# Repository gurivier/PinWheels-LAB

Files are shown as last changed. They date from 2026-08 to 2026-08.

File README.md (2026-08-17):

# PinWheels@LAB

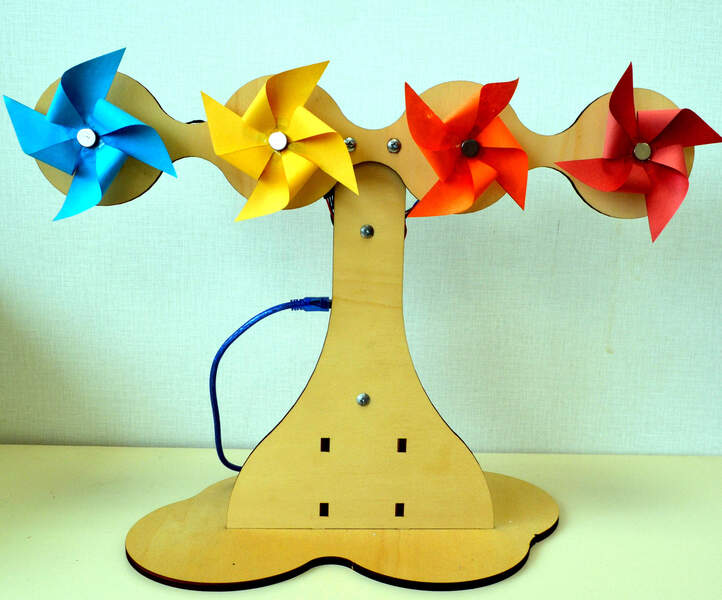
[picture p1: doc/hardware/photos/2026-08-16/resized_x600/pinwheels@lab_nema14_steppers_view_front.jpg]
Photo of a PinWheels@LAB specimen built in March 2023.


**PinWheels@LAB** is a display device that rotates four pinwheels to convey information ambiently. This small device, that teachers can bring into the classroom or install in school labs, is a tribute to the PinWheels installation<sup>(1)</sup> from the MIT Tangible Media Lab. Beyond extending Python programming lessons to data treatment and IoT communication, PinWheels@LAB enables students' thinking about innovative ways to convey information and to feel physical data representation in their classroom.

(1) Hiroshi Ishii, Sandia Ren, and Phil Frei. 2001. Pinwheels: visualizing information flow in an architectural space. In CHI '01 Extended Abstracts on Human Factors in Computing Systems (CHI EA '01). Association for Computing Machinery, New York, NY, USA, 111–112. [https://doi.org/10.1145/634067.634135](https://doi.org/10.1145/634067.634135)

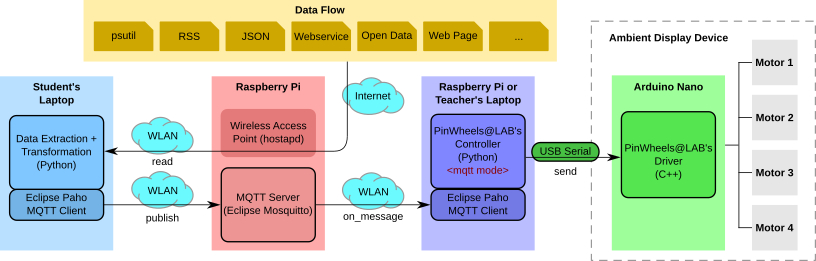
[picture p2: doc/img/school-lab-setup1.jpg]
Overview of the communication layers of PinWheels@LAB in a school lab: the student's laptop runs an application that sends messages to an MQTT brocker, which then distributes this message to PinWheels@LAB's Python controller on the teacher's laptop. Then, the controller sends the message to PinWhee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


_Bring an ambient display in the classroom!_

## Getting Started

### Prerequisites

* Python &ge; 3.15 is required ([downloads](https://www.python.org/downloads/))
  * The controller has been tested on Python version 3.15.5.

* Eclipse Mosquitto server &ge; 2.0 ([downloads](https://mosquitto.org))
    * The controller has been tested with Mosquitto version 2.0.21 and Callback API version 2
    * Check configuration in the mosquitto.conf file (e.g., `/etc/mosquitto/mosquitto.conf`):
        * `listener 1883 0.0.0.0`
        * `allow_anonymous true`

* Arduino IDE &ge; 1.8 ([downloads](https://docs.arduino.cc/software/ide/))
  * The driver has been tested on Arduino IDE 1.8.19
  * Packages:
      * digitalWriteFast 1.2.0
      * Protothreads 1.4.0-arduino.beta1

### Hardware requirements

* Fabrication
  * [2×] Plywood planks of 6-mm thickness (300 × 600 mm)
  
* Mechanics
  * [4×] Nuts and bolts: M3 L16
  * [4×] Magnets
  * [4×] Collars: D5
  * [16×] Bolts: M3 L10

* Mechatronics
  * [4×] Nema14 stepper motors: 14HS11-1004S
  * [4×] Stepper drivers: Pololu A4988

* Electronics
  * [1×] Arduino Nano
  * [4×] Capacitors: 100 µF
  * [3×] Breadboards: 170 points (55 × 30 mm)
  * [1×] Two-way terminal block
  * [1x] Power supply: 18V 2A

* Computers
  * [0×, 1×, or 2×] Raspberry Pi 3 ou 4 (see five [possible setups](./doc/communication/communication-diagram.svg))
  * [1×] USB adapter or conversion cable
    * If Arduino Nano "Genuine" or "Clone": Type-A / Mini Type-B
    * If Seeduino Nano: Type-A / Type-C
  * [1×] USB extension cable: Type-A / Type-A (e.g., length of 1 m)

### Installation

You can get the latest versions by [zip download](https://github.com/gurivier/PinWheels-LAB/archive/refs/heads/main.zip) or by git clone:

`git clone https://github.com/gurivier/PinWheels-LAB.git`

Releases are available from [releases list](https://github.com/gurivier/PinWheels-LAB/releases).

#### Dependencies

`pip3 install paho-mqtt serial`

### Help

Print general help page: `python3 pinwheels_lab.run.py -h`

Print a command's help: `python3 pinwheels_lab.run.py <command> -h`
* Available commands: `mqtt`, `prompt`, `demo`

## Author

Guillaume Rivière, [ESTIA](https://www.estia.fr), France. ([@gurivier](https://github.com/gurivier/))

## License

Source code is released under the [MIT](https://choosealicense.com/licenses/mit/) license.

Fabrication files are released under the [CC BY-SA 4.0](https://creativecommons.org/licenses/by-sa/4.0/) license.

Documentation is released under the [CC BY-SA 4.0](https://creativecommons.org/licenses/by-sa/4.0/) license.

## Versions' History

* 0.9.1 (2026-08-17)
  * Adding shell scripts for MQTT supervision and testing
* 0.9.0 (2026-08-16): First publication
  * This first publication includes:
     * `doc/`: documentation for electronics (wiring), communication (5 possible setups), hardware (photos of the device), and classroom (setup's description for students)
     * `fab/`: files for printing and folding pinwheels from paper sheets (folding patterns), and fabrication of wooden parts by laser cutting (SVG, DXF, and PS files) for NEMA14 stepper motors
     * `src/`: the source files for the Python controller and the C++ Arduino driver

---
CC BY-SA 4.0 (https://creativecommons.org/licenses/by-sa/4.0/) Guillaume Rivière, 2021-2026, [ESTIA](https://www.estia.fr), France.

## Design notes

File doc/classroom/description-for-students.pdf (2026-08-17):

WLAN

Internet

## PinWheels@LAB

Instructions:
- All the toolchain is already built.
- Your work is to develop the missing Python script of the APPLICATIVE PART that handles data treatment and sends messages to the displaying device.

Data Flow

psutil | RSS | JSON | Webservice | Open Data | Web Page | ...

Motor 1

Motor 3

Motor 4

Motor 2

Ambient Display Device

Arduino Nano

PinWheels@LAB's
Driver
(C++) send

USB Serial

Teacher's Laptop

PinWheels@LAB's
Controller
(Python)

Eclipse Paho
MQTT Client

Messages' structure

To change speed: send 5 digits + separator ("|")
- ASCII: NXYYY|
with: N = motor number in [1, 4], or 0 for all motors and: X.YYY = speed in range [ 0.000, 1.000 ]
- E.g.: "20500|" => motor 2, speed 0.5
- Reverse rotation is also implemented: N-XYYY|

WLAN

on_message

Student's Laptop | Raspberry Pi

APPLICATION =
Data Extraction +
Transformation
(Python)

Eclipse Paho
MQTT Client

WLAN

read

publish

Wireless Access
Point (hostapd)
SSID: pinwheels-lab
Passwd: Hiroshi64210
Host: 10.3.141.1

MQTT Server
(Eclipse Mosquitto)
Port: 1883
Topic: topic-pinwheels

Resources:
- https://eclipse.dev/paho/
- https://pypi.org/project/paho-mqtt/
- https://docs.python.org/fr/3/library/pickle.html

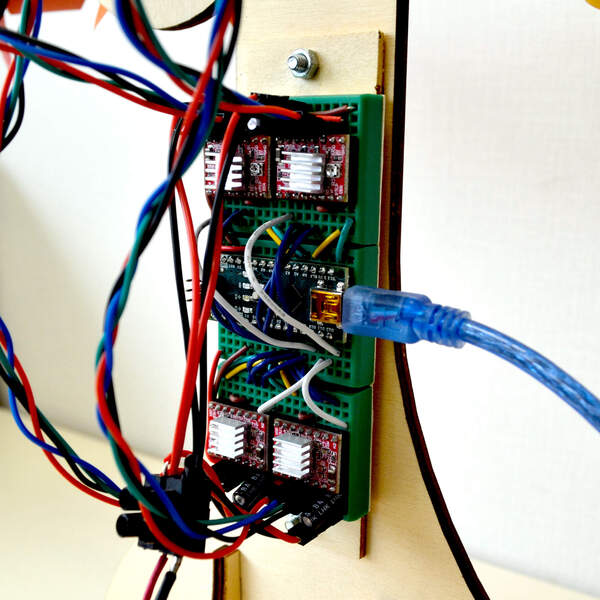
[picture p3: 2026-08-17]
doc/hardware/photos/2026-08-16/resized_x600/pinwheels@lab_nema14_steppers_view_electronics.jpg

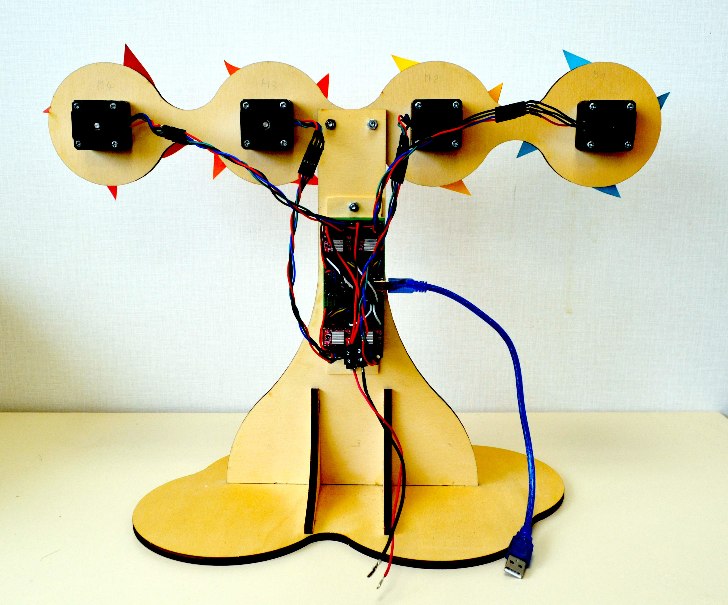
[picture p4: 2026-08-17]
doc/hardware/photos/2026-08-16/original_x2700/pinwheels@lab_nema14_steppers_view_rear.jpg

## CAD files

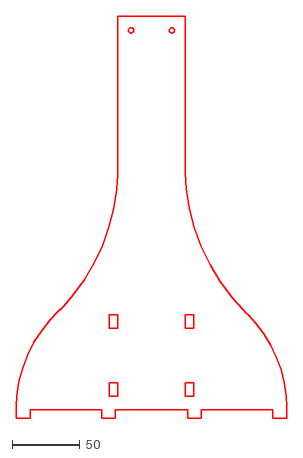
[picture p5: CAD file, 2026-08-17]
fab/stepper-motors-nema14/partB.dxf
199.9 x 296.6

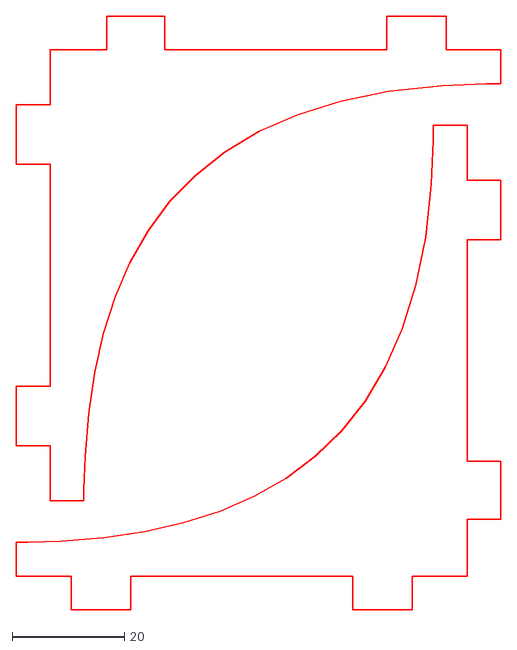
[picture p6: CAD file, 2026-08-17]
fab/stepper-motors-nema14/partC.dxf
86.2 x 105.6

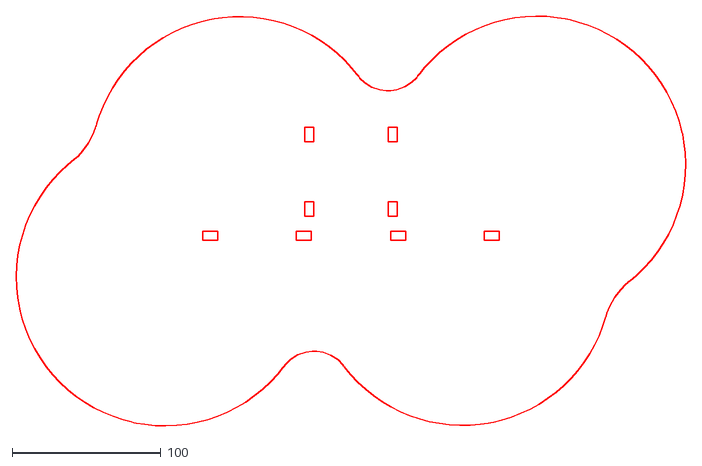
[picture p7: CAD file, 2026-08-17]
fab/stepper-motors-nema14/partD.dxf
449.9 x 275.4

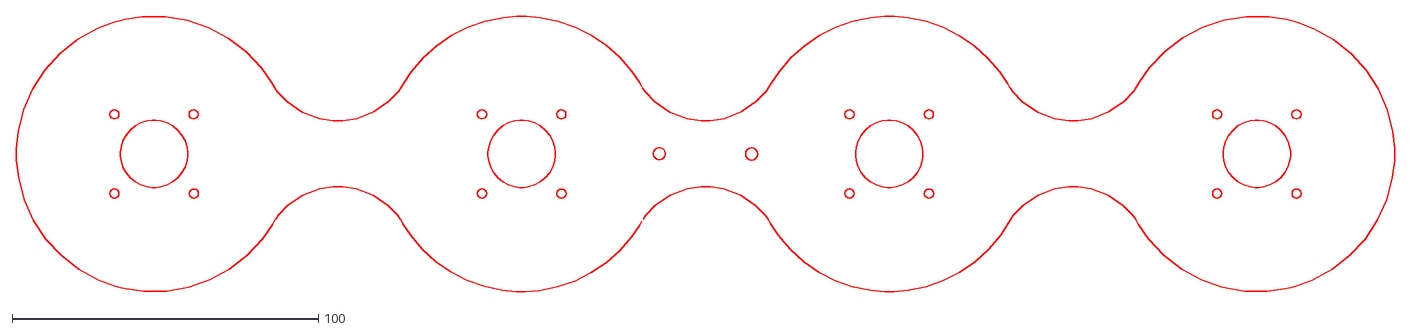
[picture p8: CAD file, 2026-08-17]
fab/stepper-motors-nema14/partA.dxf
450.0 x 89.9

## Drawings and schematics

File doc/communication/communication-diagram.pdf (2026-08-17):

## PinWheels@LAB's Communication Layers

@SCHOOL LAB Data Flow psutil RSS JSON Webservice Open Data | Setup 1 Web Page ... Ambient Display Device

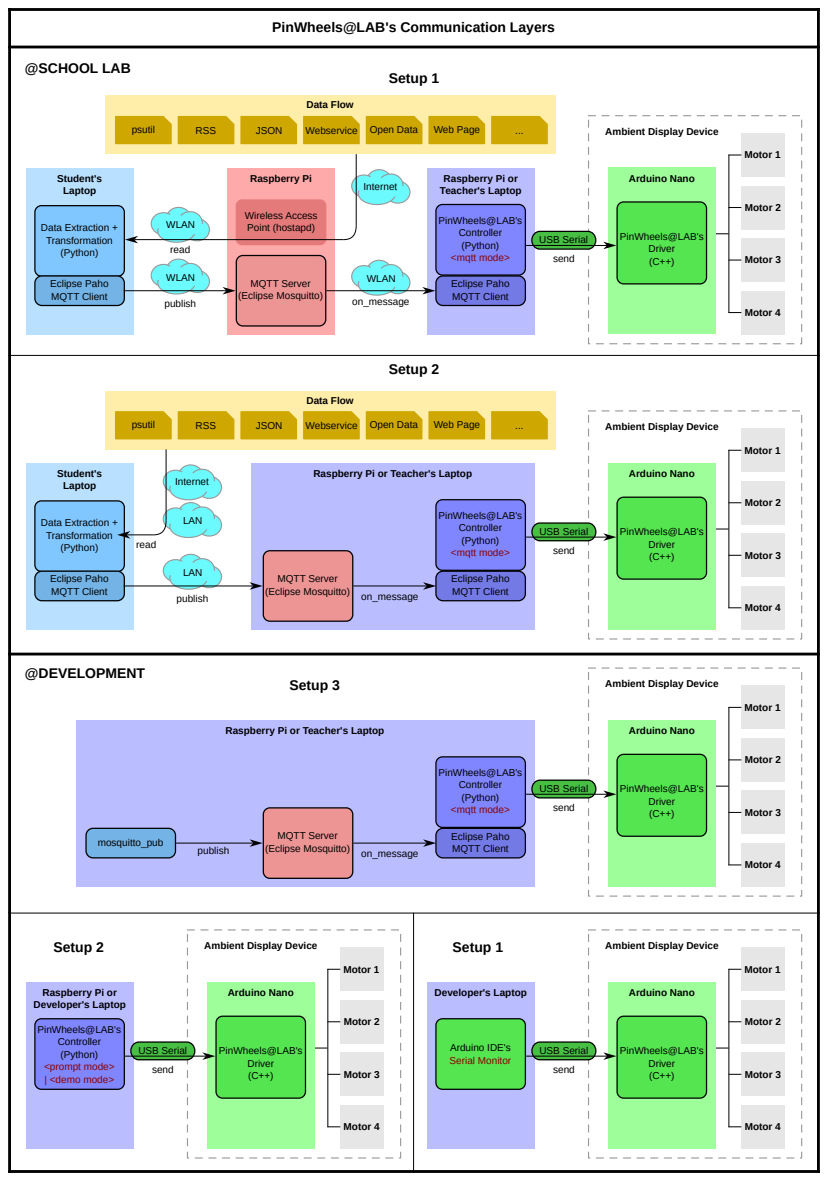
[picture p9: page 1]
Motor 1; Motor 3; Motor 4; Motor 2; WLAN; Raspberry Pi; MQTT Server (Eclipse Mosquitto); Wireless Access Point (hostapd); PinWheels@LAB's Controller (Python) <mqtt mode>; Eclipse Paho MQTT Client; Arduino Nano; PinWheels@LAB's Driver (C++) send; Student's Laptop; Data Extraction + Transformation (Python); read; publish; on_message; Internet; USB Serial; LAN; PinWheels@LAB's Driver (C++); PinWheels@LAB's Controller (Python); <mqtt mode>; send; mosquitto_pub; Developer's Laptop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

Raspberry Pi or
Teacher's Laptop

psutil | Setup 2 Data Flow RSS JSON Webservice Open Data Web Page ... Ambient Display Device

Raspberry Pi or Teacher's Laptop

@DEVELOPMENT Setup 3 Ambient Display Device

Setup 2 Ambient Display Device | | Setup 1 Ambient Display Device

Developer's Laptop

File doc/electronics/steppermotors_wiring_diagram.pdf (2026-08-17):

M4 | M3 | M1M2

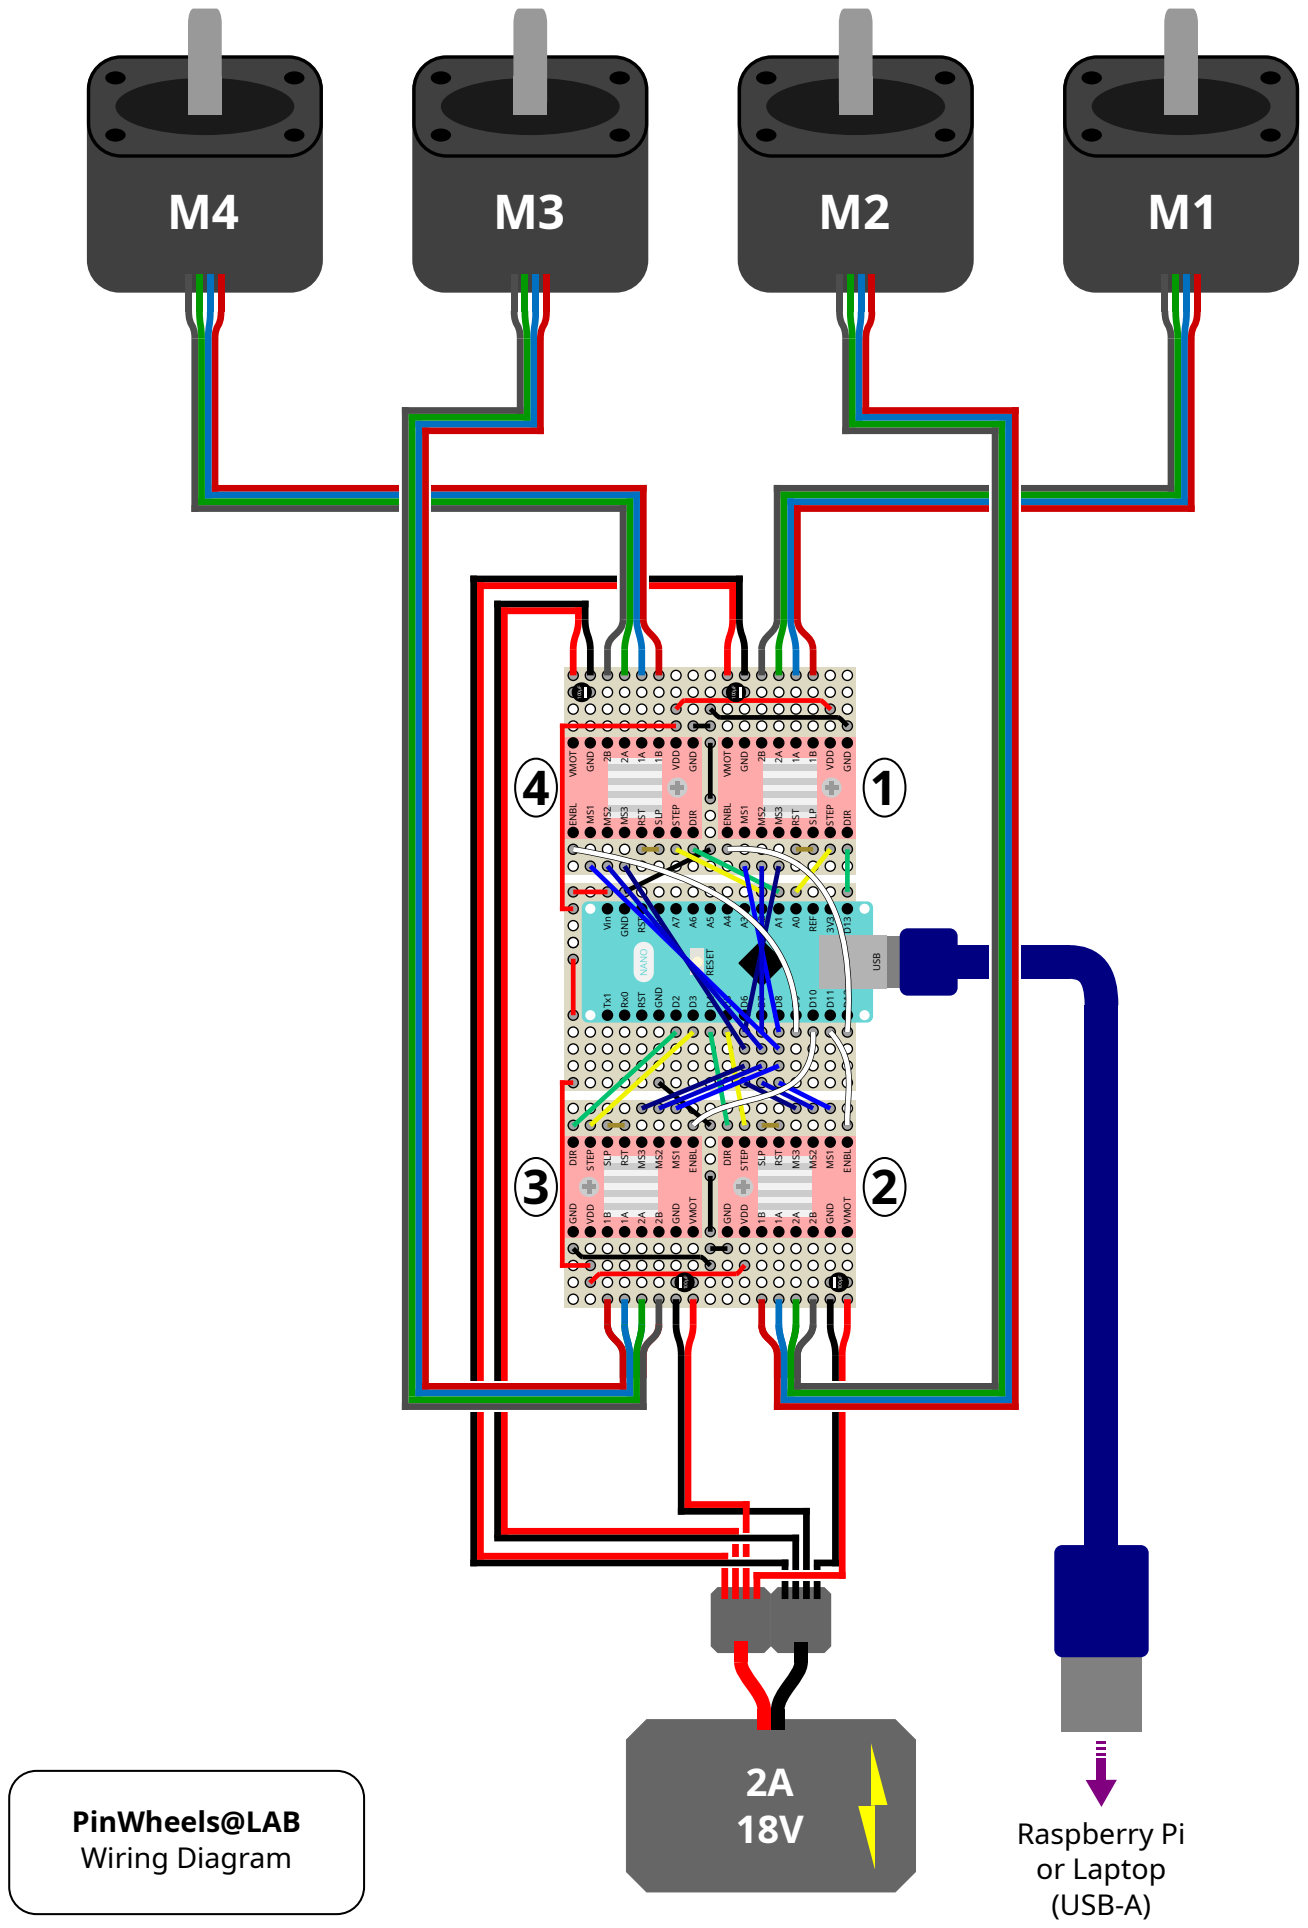
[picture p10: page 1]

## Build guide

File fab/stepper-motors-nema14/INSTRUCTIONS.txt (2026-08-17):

LASER CUTTING

>> Plywood with thickness of 6 mm

ASSEMBLY STEPS

1) Prepare the TRUNC by flush mounting parts C in the slots of part B.

2) Then, fix on the BASIS by flush mounting the TRUNC in the slots of part A.

3) Then, use nuts and bolts (M3) to fix part A at the top front of part B.

NOTES

* Files edited from Inkscape

* DXF files converted using MiConv.com

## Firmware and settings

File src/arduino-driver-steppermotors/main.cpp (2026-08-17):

/* The Arduino Nano program of PinWheels@LAB.
 *
 * File: main.cpp
 * Author: Guillaume RIVIERE
 * Date: February 2021, May 2023, August 2026
 */ 

#include <Arduino.h>
#include <pt.h>
#include <digitalWriteFast.h>

//== Arduino pinout

#define STEP_OUTPIN_M1 A0
#define STEP_OUTPIN_M2  5
#define STEP_OUTPIN_M3  3
#define STEP_OUTPIN_M4 A2

#define DIR_OUTPIN_M1  13
#define DIR_OUTPIN_M2   4
#define DIR_OUTPIN_M3   2
#define DIR_OUTPIN_M4  A1

#define ENBL_OUTPIN_M1 12
#define ENBL_OUTPIN_M2 11
#define ENBL_OUTPIN_M3 10
#define ENBL_OUTPIN_M4  9

#define MS1_OUTPIN 8
#define MS2_OUTPIN 7
#define MS3_OUTPIN 6

//== Parameters

#define DELAY_MIN_US     6000
#define DELAY_MAX_US       20
#define DELAY_DEFAULT_US 5000

//== Data structures

struct pt_param {
  struct pt proto_thread;
  uint8_t motor_index;
};

struct motor {
  uint8_t step_outpin;
  uint8_t dir_outpin;
  uint8_t enbl_outpin;
  uint16_t period_us;
  bool enabled;
  struct pt_param thread;
};

//== Macro-functions

#define PT_PARAM_INIT(_pt_param, _motor_index)           \
  PT_INIT(&_pt_param.proto_thread) ;                     \
  _pt_param.motor_index = _motor_index ;

//== Variables

struct motor motors[4];
uint8_t is_reading_frame;

//== Functions

static int proto_thread_execution(struct pt_param *thread)
{
  static uint32_t lastTimeMove[4];
  
  PT_BEGIN(&thread->proto_thread);

  //-- Impulse a motor step
  
  while (1) {
    
    lastTimeMove[thread->motor_index] = micros();
    PT_WAIT_UNTIL(&thread->proto_thread, micros() - lastTimeMove[thread->motor_index] > motors[thread->motor_index].period_us);
    digitalWriteFast(motors[thread->motor_index].step_outpin, HIGH);
    
    lastTimeMove[thread->motor_index] = micros();
    PT_WAIT_UNTIL(&thread->proto_thread, micros() - lastTimeMove[thread->motor_index] > motors[thread->motor_index].period_us);
    digitalWriteFast(motors[thread->motor_index].step_outpin, LOW);
  }
  
  PT_END(&thread->proto_thread);
}

uint16_t speed_to_period_us(double factor)
{
  return DELAY_MAX_US + (DELAY_MIN_US - DELAY_MAX_US) * (1.0 - factor) ;
}

int16_t read_digit()
{
  int16_t res;
  
  while (!(isdigit(res = Serial.read()) || res == '-'));
  
  return res;
}

void setup ()
{
  is_reading_frame = 0;
  
  Serial.begin(9600);

  delay(5000);
  
  //-- Set motors' pinout
  
  motors[0].step_outpin = STEP_OUTPIN_M1;
  motors[0].dir_outpin = DIR_OUTPIN_M1;
  motors[0].enbl_outpin = ENBL_OUTPIN_M1;

  motors[1].step_outpin = STEP_OUTPIN_M2;
  motors[1].dir_outpin = DIR_OUTPIN_M2;
  motors[1].enbl_outpin = ENBL_OUTPIN_M2;

  motors[2].step_outpin = STEP_OUTPIN_M3;
  motors[2].dir_outpin = DIR_OUTPIN_M3;
  motors[2].enbl_outpin = ENBL_OUTPIN_M3;

  motors[3].step_outpin = STEP_OUTPIN_M4;
  motors[3].dir_outpin = DIR_OUTPIN_M4;
  motors[3].enbl_outpin = ENBL_OUTPIN_M4;
  
  //-- Init micro-stepping pins ( 1/16 stepping => [ HIGH, HIGH, HIGH ])

  pinMode(MS1_OUTPIN, OUTPUT) ;
  pinMode(MS2_OUTPIN, OUTPUT) ;
  pinMode(MS3_OUTPIN, OUTPUT) ;
  
  digitalWrite(MS1_OUTPIN, HIGH) ;
  digitalWrite(MS2_OUTPIN, HIGH) ;
  digitalWrite(MS3_OUTPIN, HIGH) ;
  
  //-- Init values

  for (uint8_t i = 0 ; i < 4 ; i++) {

    //-- Init proto-thread
    
    PT_PARAM_INIT(motors[i].thread, i);
    
    //-- Init step and dir pins
    
    pinMode(motors[i].step_outpin, OUTPUT) ;
    pinMode(motors[i].dir_outpin, OUTPUT) ;
  
    //-- Disable power supply
    
    bool is_running = false;
    motors[i].enabled = is_running ;
    pinMode(motors[i].enbl_outpin, OUTPUT) ;
    digitalWrite(motors[i].enbl_outpin, is_running ? LOW : HIGH) ;
    
    //-- Set motor speed
    
    motors[i].period_us = DELAY_DEFAULT_US ;
    
    //-- Set motor direction
    
    digitalWrite(motors[i].dir_outpin, HIGH) ;
  }

  Serial.println("Setup done. Waiting.");
}

void loop ()
{  
  //-- Rotate motors

  for (uint8_t i = 0 ; i < 4 ; i++) {
    if (motors[i].enabled) {
      proto_thread_execution(&motors[i].thread);
    }
  }
  
  //-- Read from serial
  
  if (Serial.available() > 0) {
    static uint8_t cur_motor, speed_0, speed_1, speed_2, speed_3, dir ; 
    static double speed ;
    static int16_t b ;

    //** Frame reading is splitted into 8 steps that are distributed over successive loop iterations
    //** (in order to interleave frame reading with threads execution and preserve motors' rotation)
    
    if (is_reading_frame == 0) {
      while (Serial.available() > 0 && is_reading_frame == 0) {

        //** STEP 1: Seek a motor value
        
        b = Serial.read() - '0' ;
        
        if (b >= 0 && b <= 4) {          
          cur_motor = b;
          
          //-- Start frame reading
          is_reading_frame++;
        }
      }
    }
    else if (is_reading_frame == 1) {

      //** STEP 2: Read direction and 1st speed digit
      
      b = read_digit() ;
      
      if (b == '-') {
        dir = LOW ; // reverse
        b = read_digit() ;
      }
      else {
        dir = HIGH ; // normal
      }
      
      speed_0 = b - '0' ;
      
      is_reading_frame++;
    }
    else if (is_reading_frame == 2) {

      //** STEP 3:  Read direction 2nd speed digit

      speed_1 = read_digit() - '0' ;
      is_reading_frame++;
    }
    else if (is_reading_frame == 3) {

      //** STEP 4:  Read direction 3rd speed digit
      
      speed_2 = read_digit() - '0' ;
      is_reading_frame++;
    }
    else if (is_reading_frame == 4) {

      //** STEP 5:  Read direction 4th speed digit

      speed_3 = read_digit() - '0' ;
      is_reading_frame++;
    }
    else if (is_reading_frame == 5) {
      
      //** STEP 6:  Calculate speed
      
      speed = speed_0 + speed_1 * 0.1 + speed_2 * 0.01 + speed_3 * 0.001 ;

      if (speed > 1.0) {
        speed = 1.0 ;
      }
      
      if (speed < 0.0) {
        speed = 0.0 ;
      }

      is_reading_frame++;
    }
    else if (is_reading_frame == 6) {

      //** STEP 7:  Update motors' parameters
      
      for (uint8_t motor_number = 1 ; motor_number <= 4 ; motor_number++) {
        if (motor_number == cur_motor || cur_motor == 0) {
          struct motor *motor = &motors[motor_number - 1];
          
          //-- Enable or disable motor
          motor->enabled = (speed > 0.0) ;
          digitalWriteFast(motor->enbl_outpin, motor->enabled ? LOW : HIGH) ;
          
          //-- Motor speed
          motor->period_us = speed_to_period_us (speed) ;
          
          //-- Motor direction
          digitalWriteFast(motor->dir_outpin, dir) ;
        }
      }
      
      is_reading_frame++;
    }
    else if (is_reading_frame == 7) {

      //** STEP 8: Seek frame end
      
      while (Serial.read() != '|') ;

      //-- End frame reading
      is_reading_frame = 0 ;
    }
  }

}

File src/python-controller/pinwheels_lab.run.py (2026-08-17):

#!/usr/bin/env python3

"""
The Python controller of PinWheels@LAB.

File: pinwheels_lab.py
Author: Guillaume RIVIERE
Date: February 2021, May 2023, August 2026
"""

import time

from pw_arduino_client import arduino_init, arduino_send, arduino_stop

pname = 'PinWheels@LAB'

def get_program_parameters():
    import argparse, textwrap
    
    parser = argparse.ArgumentParser(
        prog='PinWheels@LAB: Raspberry Pi Client',
        description='This program drives PinWheels@LAB.',
        epilog='Guillaume RIVIERE, 2021-2026')
    
    subparsers = parser.add_subparsers(dest="subparser_name", help='sub-command help')
    
    parsers = {
        'mqtt': subparsers.add_parser('mqtt', help="Execute the messages from an MQTT broker."),
        'prompt': subparsers.add_parser('prompt', help="Execute the messages from user input."),
        'demo': subparsers.add_parser('demo', help="Execute some predefined messages for demonstration.")
    }

    parsers['mqtt'].add_argument('--host', type=str, nargs=1, required=False, help='Host of the MQTT broker (hostname or IP address).')
    
    information = textwrap.dedent(f'''\
    further information:
      project directory    https://github.com/gurivier/PinWheels-LAB
      documentation        https://github.com/gurivier/PinWheels-LAB/wiki
    ''')
    
    usages = ''.join(['  '+p.format_usage().strip('usage: ') for p in parsers.values()])
    parser.formatter_class = argparse.RawTextHelpFormatter
    parser.epilog = textwrap.dedent(f'commands usage:\n{usages}\n{information}')
    
    for subparser in parsers.values():
        subparser.formatter_class = argparse.RawTextHelpFormatter
        subparser.epilog = information
        
    return parser.parse_args()

def usage():
    print('Use option --help to display usage.')
    
def help():
    print('---')
    print('Examples of valid messages:')
    print('  * One frame:        NXYYY|')
    print('  * Several frames:   NXYYY|NXYYY|NXYYY|')
    print('  * Reverse rotation: N-XYYY|')
    print('  * Quit:             q')    
    print('with:')
    print('  * N in [0..4]')
    print('  * X.YYY in [0.000 .. 1.000]')
    print('---')

def run_demo():
    arduino_send('10500|')
    time.sleep(2.0)
    arduino_send('20500|')
    time.sleep(2.0)
    arduino_send('30500|')
    time.sleep(2.0)
    arduino_send('40500|')
    time.sleep(3.0)
    arduino_send('00900|')
    time.sleep(3.0)
    arduino_stop()
    print('End.')

def run_from_prompt():
    prompting = True
    print('>> PROMPT MODE <<')
    help()
    while (prompting):
        prompt = input('Give bytes: ')
        if prompt != 'q':
            arduino_send(prompt)
        else:
            arduino_stop()
            prompting = False
    print('End.')            

def run_from_mqtt(host):
    import paho.mqtt.client as mqtt

    #host = '10.3.141.1'
    port  = 1883
    topic = 'topic-pinwheels'
    
    def on_connect(client, userdata, flags, reason_code, properties):
        print(f"Connected with result code {reason_code}")
        client.subscribe(topic, qos=2)
 
    def on_message(client, userdata, databytes):
        message = str(databytes.payload.decode())
        if message == 'q':
            arduino_stop()
            client.disconnect()
        else:
            arduino_send(message)

    client = mqtt.Client(mqtt.CallbackAPIVersion.VERSION2)
    client.on_connect = on_connect
    client.on_message = on_message
    print(f"Connecting to MQTT host: {host}")
    client.connect(host, port, 60)
    client.loop_forever()
    print('End.')
        
def main():
    args = get_program_parameters()
    if args.subparser_name is not None:
        arduino_init()
    if args.subparser_name == 'mqtt':
        host = args.host[0] if args.host is not None else '127.0.0.1'
        run_from_mqtt(host)
    elif args.subparser_name == 'prompt':
        run_from_prompt()
    elif args.subparser_name == 'demo':
        run_demo()
    else:
        usage()

if __name__ == '__main__':
    import sys
    exit_code = main()
    sys.exit(exit_code)

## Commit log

2026-08-17 First version of 2026-08-16 (0.9.0).
    This first publication includes:
    * doc/: documentation for electronics (wiring), communication (5 possible setups), hardware (photos of the device), and classroom (setup's description for students)
    * fab/: files for printing and folding pinwheels from paper sheets (folding patterns), and fabrication of wooden parts by laser cutting (SVG, DXF, and PS files) for NEMA14 stepper motors
    * src/: the source files for the Python controller and the C++ Arduino driver
    [partA.dxf, partB.dxf, partC.dxf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]
2026-08-17 update: readme and assembly instructions
